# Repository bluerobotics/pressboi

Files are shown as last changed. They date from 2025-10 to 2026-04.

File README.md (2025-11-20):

<div align="center">

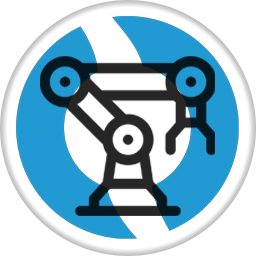
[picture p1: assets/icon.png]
Pressboi


# Pressboi

**Dual-Motor Press Control System**






[View Changelog](CHANGELOG.md) • [Download Latest Release](https://github.com/bluerobotics/pressboi/releases/latest)

</div>

---

## Overview

Firmware for the Pressboi dual-motor press control system, built on the Teknic ClearCore platform. This firmware provides precision control for press operations with real-time force monitoring, synchronized dual-motor movement, and network/USB communication.

**Designed to work with:** [BR Equipment Control App](https://github.com/bluerobotics/br-equipment-control-app) - A Python/Tkinter GUI for controlling and monitoring the Pressboi and other Blue Robotics manufacturing equipment.

## Features

- **Dual-motor synchronized control** - Two motors on a single axis for press operations
- **UDP/Ethernet communication** - Network-based control with device discovery
- **USB Serial fallback** - Direct USB communication support
- **Command-based control** - Simple text-based command protocol
- **Real-time telemetry** - Position, force, torque, and status reporting
- **Pause/resume/cancel** - Interrupt and resume operations safely
- **Force monitoring** - Real-time force feedback with configurable limits
- **Auto-generated protocol** - Commands and telemetry from JSON schemas

---

## Building

### Requirements

- **Atmel Studio 7** (Windows) or compatible ARM GCC toolchain
- **Teknic ClearCore libraries** (included as submodules/dependencies)
  - `libClearCore`
  - `LwIP` (Lightweight IP stack)

### Build Instructions

1. Open `pressboi.atsln` in Atmel Studio
2. Ensure libraries are properly referenced:
   - `lib/libClearCore/ClearCore.cppproj`
   - `lib/LwIP/LwIP.cppproj`
3. Select build configuration (Debug or Release)
4. Build the solution (F7)

### Output Files

- `Debug/pressboi.bin` - Binary firmware image
- `Debug/pressboi.uf2` - UF2 format for bootloader flashing

### Flashing

### Via BR Equipment Control App (Recommended for Updates)

The easiest way to update firmware on an already-running device is through the [BR Equipment Control App](https://github.com/bluerobotics/br-equipment-control-app):

1. Open the Firmware Manager in the app
2. Select your device
3. Choose the firmware file or download the latest release
4. Click "Update Firmware" - the app handles the entire flashing process automatically

**Note:** Firmware flashing is only supported over USB connections. For initial flashing of a new device, use the bootloader method below.

### Via Bootloader (For Initial Flashing)

For initial flashing of a new device or when the app is not available:

1. Put the ClearCore into bootloader mode (hold button during power-on)
2. Copy `pressboi.uf2` to the mounted bootloader drive
3. The device will automatically reboot with new firmware

### Via Atmel Studio

1. Connect ClearCore via USB
2. Select "Custom Programming Tool" in project settings
3. Build and program (F5)

---

## Communication Protocol

The firmware uses a simple text-based command protocol over UDP or USB serial:

- Commands: `move_abs <position> mm`, `move_inc <distance> mm`, `home`, `enable`, `disable`
- Status: `DONE: <command>`, `ERROR: <message>`, `INFO: <message>`
- Telemetry: Periodic status updates with position, force, torque, and motor status

See the [BR Equipment Control App](https://github.com/bluerobotics/br-equipment-control-app) for full protocol documentation and command reference.

---

## Hardware Configuration

### Motors
- **Motor A**: Primary press motor (M0)
- **Motor B**: Secondary press motor (M1) - synchronized with Motor A

### Sensors
- **Force sensor**: Load cell or motor torque-based force monitoring
- **Position feedback**: Encoder feedback from ClearPath motors

## Configuration

Key parameters can be configured in `inc/config.h`:

- **Motor parameters**: Steps per mm, velocities, accelerations, torque limits
- **Homing parameters**: Velocities, accelerations, torque limits, backoff distances
- **Force monitoring**: Force limits, sensor calibration, enable/disable options
- **Network settings**: UDP port, packet sizes, telemetry interval

---

## Contributing

For issues, feature requests, or contributions, please open an issue or pull request on GitHub.

---

<div align="center">

⭐ **Star us on GitHub if you found this useful!**

Made with 💙 by the Blue Robotics team and contributors worldwide

---

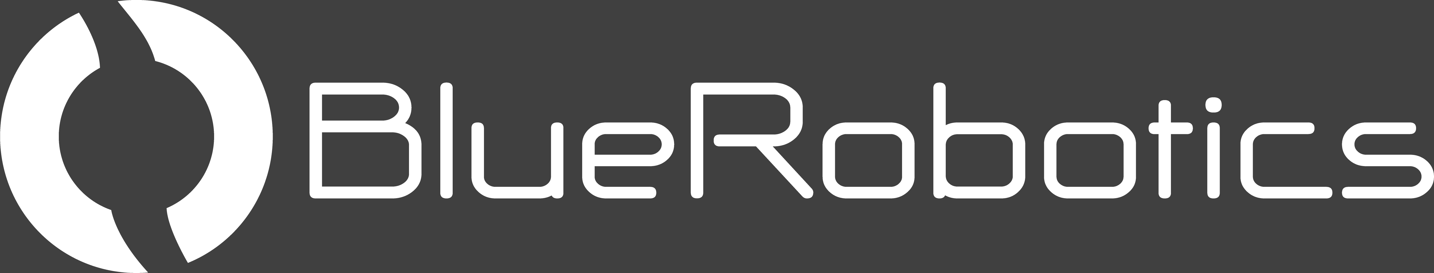
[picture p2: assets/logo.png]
Blue Robotics


**[bluerobotics.com](https://bluerobotics.com)** | Manufacturing Equipment Control

</div>

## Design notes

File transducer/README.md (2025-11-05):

# HX711 Force Transducer Interface

Rugeduino (Arduino Uno) firmware for interfacing HX711 load cell amplifier with Pressboi ClearCore controller.

## Hardware Required

- **Ruggeduino-SE ST** (Screw Terminal version - ruggedized Arduino Uno)
- **HX711 Load Cell Amplifier Module**
- **Load Cell** (configured for force measurement)
- 22-24 AWG wire for screw terminal connections

## Wiring

### Load Cell → HX711

```
Load Cell Color    HX711 Pin
---------------    ---------
Red (E+)       →   E+
Black (E-)     →   E-
White (A-)     →   A-
Green (A+)     →   A+
```

### HX711 → Ruggeduino-SE

**Use the screw terminals - no soldering required!**

```
HX711 Pin      Ruggeduino-SE Screw Terminal
---------      ----------------------------
VCC        →   5V
GND        →   GND
DOUT       →   D3
SCK        →   D2
RATE       →   5V (enables 80Hz mode; leave disconnected for 10Hz)
```

### Rugeduino → ClearCore COM-0

**ClearCore COM-0 must be configured in TTL mode!**

```
Ruggeduino-SE Pin    ClearCore COM-0 (8-pin connector)         Wire Color
-----------------    ----------------------------------         ----------
D1 (TX)          →   Pin 8 (Data In / COM0 RX)                 Brown
D0 (RX)          →   Pin 5 (Data Out / COM0 TX)                Green/White
GND              →   Pin 4 (GND)                               Blue
VIN or 5V        →   Pin 6 (5V Power) ⚡ 450mA available       Green
```

**Note:** 
- The ClearCore COM-0 port can power the Ruggeduino-SE directly (up to 450mA available from 5VOB). Connect to VIN or 5V screw terminal. Ruggeduino draws ~50mA typical.
- **During USB programming:** Disconnect D0/D1 from ClearCore to avoid conflicts with USB serial

## Software Setup

### Arduino

1. Install the **HX711 library** by Bogde:
   - Arduino IDE → Tools → Manage Libraries
   - Search "HX711"
   - Install "HX711 by Bogde"

2. Upload `hx711_nano.ino` to the Ruggeduino-SE
   - **Important:** Disconnect D0/D1 from ClearCore during USB upload

3. **Calibrate the scale:**
   - Set `calibration_factor = 1.0` initially
   - Place a known weight (e.g., 10 kg) on the load cell
   - Read the output in Serial Monitor
   - Calculate: `calibration_factor = output_value / 10.0`
   - Update the code and re-upload

### ClearCore

The force sensor is integrated into the pressboi firmware:
- `force_sensor.h` / `force_sensor.cpp` - Force sensor class
- COM-0 configured as TTL UART at 115200 baud
- Force readings automatically appear in telemetry

## Serial Protocol

### Arduino → ClearCore (Continuous Output)

**Format:** Simple floating point value in kg  
**Example:** `12.34\n`  
**Rate:** 80Hz (synchronized with HX711 samples when RATE pin = 5V)

### ClearCore → Arduino (Commands)

| Command | Function |
|---|---|
| `T` or `t` | Tare/zero the scale |
| `R` or `r` | Get raw ADC value (for debugging) |
| `C` or `c` | Calibration mode (future) |

## Calibration Procedure

1. **Tare with no load:**
   - Remove all weight from load cell
   - Send 'T' command or power cycle
   - Reading should be ~0.00 kg

2. **Determine calibration factor:**
   - Set `calibration_factor = 1.0` in code
   - Upload to Arduino
   - Place known weight (e.g., 10.00 kg)
   - Read the output value (e.g., 234567)
   - Calculate: `calibration_factor = 234567 / 10.0 = 23456.7`
   - Update code with new factor and re-upload

3. **Verify accuracy:**
   - Test with multiple known weights
   - Adjust calibration factor if needed
   - Typical accuracy: ±0.1% with proper calibration

## Troubleshooting

**No readings:**
- Check wiring connections
- Verify HX711 power (3.3V-5V)
- Check Arduino serial output in Serial Monitor
- Ensure load cell is properly connected

**Noisy/unstable readings:**
- Improve grounding
- Shorten wires between load cell and HX711
- Use shielded cable for load cell wires
- Reduce mechanical vibration

**Readings drift:**
- Allow 10-15 minutes warm-up time
- Reduce temperature variations
- Re-tare periodically

**Readings don't change with force:**
- Check load cell wiring (especially A+/A-)
- Verify load cell is mechanically loaded correctly
- Check calibration factor

## References

- **HX711 Datasheet:** https://cdn.sparkfun.com/assets/b/f/5/a/e/hx711F_EN.pdf
- **HX711 Library:** https://github.com/bogde/HX711
- **SparkFun Hookup Guide:** https://learn.sparkfun.com/tutorials/load-cell-amplifier-hx711-breakout-hookup-guide

## License

MIT License - See main repository LICENSE file

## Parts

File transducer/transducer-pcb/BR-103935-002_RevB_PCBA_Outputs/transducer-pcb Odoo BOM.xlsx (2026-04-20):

External ID | Reference | Product | Quantity | BoM Type | BoM Lines/Component | BoM Lines/Quantity
mrp_bom_BR-103935-002 | BOM_PCB | BR-103935-002 | 1 | Manufacture this product | component.bre_BRE_000048 | 1
mrp_bom_BR-103935-002 | BOM_PCB | BR-103935-002 | 1 | Manufacture this product | component.bre_BRE_001269 | 1
mrp_bom_BR-103935-002 | BOM_PCB | BR-103935-002 | 1 | Manufacture this product | component.bre_BRE_001271 | 2
mrp_bom_BR-103935-002 | BOM_PCB | BR-103935-002 | 1 | Manufacture this product | component.bre_BRE_001364 | 1
mrp_bom_BR-103935-002 | BOM_PCB | BR-103935-002 | 1 | Manufacture this product | component.bre_BRE_001029 | 2
mrp_bom_BR-103935-002 | BOM_PCB | BR-103935-002 | 1 | Manufacture this product | component.bre_BRE_001259 | 2
mrp_bom_BR-103935-002 | BOM_PCB | BR-103935-002 | 1 | Manufacture this product | component.bre_BRE_001332 | 2
mrp_bom_BR-103935-002 | BOM_PCB | BR-103935-002 | 1 | Manufacture this product | component.bre_BRE_001042 | 1

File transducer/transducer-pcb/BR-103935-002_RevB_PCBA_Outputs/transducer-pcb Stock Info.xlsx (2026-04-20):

# Boards: | 5 | <---- EDIT NUMBER OF BOARDS HERE
Project: | transducer-pcb
BR Number: | BR-103935-002 RevB
Date: | 2026-02-23T16:28:30-0800
Legend
In stock @ JLC
Low Stock @ JLC
Not Enough Stock @ JLC
Does not exist @ JLC
BRE Number | Reference | Description | Quantity/Board | Total Quantity | MPN | JLCPCB Part # | JLC Stock | Global + Consigned Stock | Alt JLC Parts | DigiKey Parts | Mouser Parts | Other Vendor Parts | Unit Cost | Cost Per Board
BRE-000048 | C1 | 1nF 1kV X7R 10% Ceramic Capacitor 0805 | 1 | 5 | 0805B102K102CT | C303890 | 900 | 0 |  | 1292-0805B102K102CT-ND | 791-0805B102K102CT |  | $0.0037 | $0.0037
BRE-001269 | J1 | 1x4P 7A 150V 2.54mm Screw Terminal Through Hole | 1 | 5 | DB125-2.54-4P-GN-S | C918122 | 80 | 940 |  |  |  |  | $0.26 | $0.26
BRE-001271 | J2, J11 | 1x2P 8A 130V 2.54mm Screw Terminal Through Hole | 2 | 10 | KF128-2.54-2P | C474920 | 90 | 0 |  |  |  |  | $0.11 | $0.21
BRE-001364 | J3 | RJ45 Receptacle Connector, Without LEDs, Unshielded | 1 | 5 | RC02015 | C708654 | 30 | 0 |  |  |  |  | $0.20 | $0.20
BRE-001029 | J4, J5 | Header Pin Connector 01x05 2.54mm (0.100") Vertical PTH | 2 | 10 | HB-PH3-25415PB2GOP | C6332198 | 75 | 0 |  |  |  |  | $0.01 | $0.03
BRE-001259 | J6, J8 | Header Pin 2P 01x02P 2.54mm Pitch Vertical Through Hole 3A | 2 | 10 | PZ254V-11-02P | C492401 | 1250 | 0 |  |  |  |  | $0.01 | $0.01
BRE-001332 | J7, J9 | Header Pin Connector 01x06 2.54mm (0.100") Vertical PTH | 2 | 10 | PZ2.54-1X6P-H25 | C42431790 | 0 | 0 |  |  |  |  | $0.00 | $0.00
BRE-001042 | J10 | Header Pin Connector 01x04 2.54mm (0.100") Vertical PTH | 1 | 5 | PZ254V-11-04P | C2691448 | 0 | 0 | C6332197, C5116483 |  |  |  | $0.00 | $0.00
 |  |  |  |  |  |  |  |  |  |  |  |  | Total BOM Cost: | $0.72
DNP Components
BRE Number | Reference | Description | Quantity/Board | Total Quantity | MPN | JLCPCB Part # | JLC Stock | Global + Consigned Stock | Alt JLC Parts | DigiKey Parts | Mouser Parts | Other Vendor Parts | Unit Cost | Cost Per Board

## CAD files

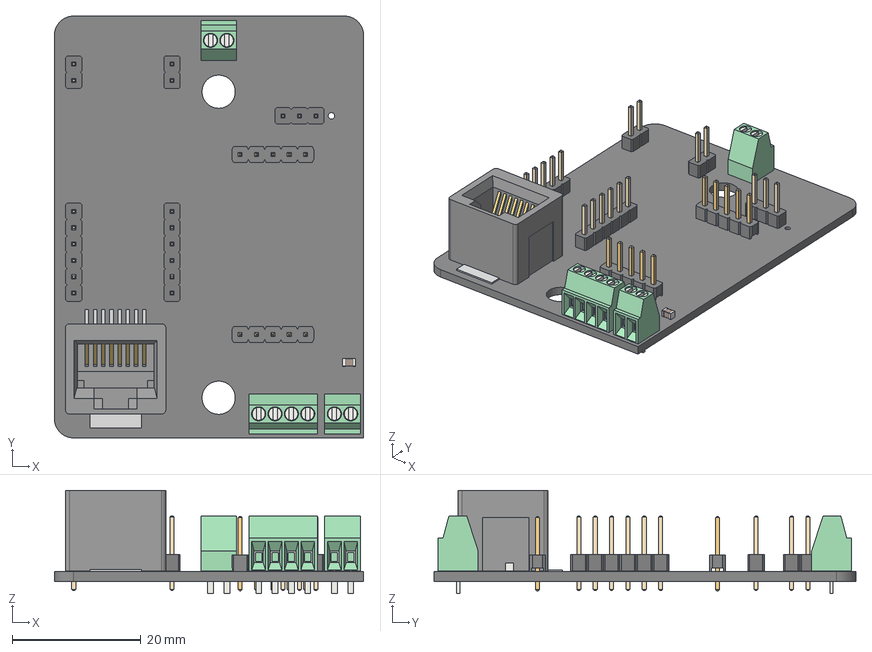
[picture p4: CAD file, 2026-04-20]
transducer/transducer-pcb/BR-103935-002_RevB_PCBA_Outputs/transducer-pcb.step
48.0 x 65.5 x 16.0 mm
PinHeader_1x06_P2.54mm_Vertical x 2
6130xx11121_PIN x 10
C_0805_2012Metric
TerminalBlock_Phoenix_MPT-0,5-2-2.54_1x02_P2.54mm_Horizontal x 2
PinHeader_1x02_P2.54mm_Vertical x 2
PinHeader_1x03_P2.54mm_Vertical
RJ45-SMD_8P-P1.27_RC02015
TerminalBlock_Phoenix_MPT-0,5-4-2.54_1x04_P2.54mm_Horizontal
transducer-pcb_PCB

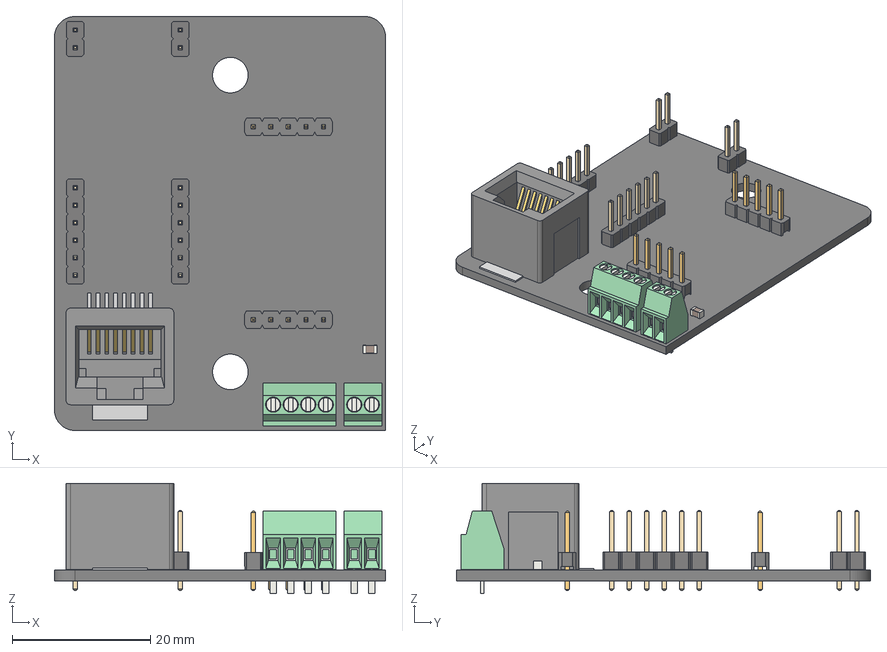
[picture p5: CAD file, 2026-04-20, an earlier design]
transducer/transducer-pcb/BR-103935-002_RevA_PCBA_Outputs/transducer-pcb.step
48.0 x 60.0 x 16.0 mm
PinHeader_1x06_P2.54mm_Vertical x 2
6130xx11121_PIN x 10
C_0805_2012Metric
PinHeader_1x02_P2.54mm_Vertical x 2
RJ45-SMD_8P-P1.27_RC02015
TerminalBlock_Phoenix_MPT-0,5-2-2.54_1x02_P2.54mm_Horizontal
TerminalBlock_Phoenix_MPT-0,5-4-2.54_1x04_P2.54mm_Horizontal
transducer-pcb_PCB

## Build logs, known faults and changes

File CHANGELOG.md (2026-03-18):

# Changelog

All notable changes to the Pressboi firmware will be documented in this file.

## [1.14.1] - 2026-03-18

### Fixed
- **NVM strain calibration persistence**: `set_strain_cal` command was writing coefficients to wrong NVM addresses (`(8+i)` instead of `(8+i)*4` byte offsets), causing calibration to be lost on reboot
- **Telemetry force display**: `force_motor_torque` telemetry was using hardcoded calibration values (1.04/0.0335) instead of NVM-stored values from `set_force_offset`/`set_force_scale` commands; also increased force clamp from 1000 kg to 2000 kg to match motor_torque mode range

### Changed
- **Dead code cleanup**: Removed unused USB mirror declarations and member variables from CommsController (~1KB RAM savings)

## [1.14.0] - 2025-11-28

### Added
- **Press Report System**: HTML report generation with interactive graphs
  - Force vs distance visualization with Plotly.js
  - 4th order polynomial fit for machine strain calibration
  - Pass/fail thresholds for force, endpoint, and energy
  - Collapsible calibration data section with copy command button
- **`set_press_threshold` command**: Configure force threshold for press detection (0.1-50.0 kg), saved to NVM
- **`set_strain_cal` command**: Set machine strain compensation coefficients, saved to NVM
- **Telemetry**: Added `startpoint`, `endpoint`, and `press_threshold` telemetry values
- **NVM Storage**: Press threshold and strain calibration coefficients persisted across reboots

### Changed
- **Default press threshold**: 2.0 kg (configurable via command)
- **Machine strain coefficients**: Updated defaults for improved energy accuracy
- **Max deflection**: Increased `MACHINE_STRAIN_MAX_DEFLECTION_MM` to 5.0mm for flexible jigs

### Fixed
- **Joules calculation**: Fixed machine strain compensation consuming all energy
- **Endpoint tracking**: Now correctly reports actual endpoint position via telemetry

## [1.13.0] - 2025-11-26

### Added
- **Operator View**: Cycle time display, error/warning status bar, "Show Stats" button
- **Operator View**: On-screen keyboard support (Mac only)
- **Operator View**: Hover effects on Run/Hold/Reset buttons matching main app

## [1.12.1] - 2025-11-26

### Changed
- **Operator View**: Redesigned press operator view with fullscreen layout, large controls, and PASS/FAIL indicator

### Fixed
- **CRITICAL: Watchdog timeout on app restart**: Delayed auto-homing by 2 seconds after boot to prevent watchdog timeout during busy startup/reconnection period when message queues are processing and USB is reconnecting

## [1.12.0] - 2025-11-26

### Added
- **`home_on_boot` command**: Configure whether press automatically homes on startup (default: true), saved to NVM
- **Retract position persistence**: `set_retract` now saves position to NVM and restores after power cycle/reboot

### Changed
- **NVM dump enhanced**: Added `HomeOnBoot` and `RetractPosition` to dump summary output

### Fixed
- **Command parsing order**: Fixed `reset_nvm` being misinterpreted as `reset` by checking longer commands first
- **Retract position restoration**: Correctly recalculates retract position after homing to prevent accumulation

## [1.11.3] - 2025-11-26

### Changed
- **Watchdog timeout increased to 256ms**: Doubled from 128ms to provide better stability during USB reconnection
- **USB chunking timeout reduced**: Lowered per-chunk timeout from 10ms to 3ms to prevent blocking (total ~30ms vs previous ~100ms)

### Fixed
- **Watchdog timeout on app restart**: Prevents main loop blocking during USB reconnection when TX queue processes large messages

## [1.11.2] - 2025-11-24

### Changed
- **NVM dump output**: Added polarity information to `dump_nvm` command summary

## [1.11.1] - 2025-11-24

### Changed
- Updated compiled binaries with latest source changes

## [1.11.0] - 2025-11-24

### Added
- **`set_polarity` command**: Allows flipping coordinate system between 'normal' and 'inverted' modes, saved to NVM

## [1.10.5] - 2025-11-21

### Fixed
- **TX queue overflow during log dumps**: Temporarily disable watchdog during `dump_error_log` command to prevent resets during large log transfers (100+ entries can take >500ms, exceeding 100ms watchdog timeout)
- **Log dump reliability**: Added 5ms delay per error entry and 50ms delay every 10 heartbeat entries to prevent TX queue overflow errors
- Watchdog disabled only for diagnostic `dump_error_log` command, maintains watchdog integrity for all normal operations

## [1.10.1] - 2025-11-20

### Added
- **Extended watchdog breadcrumbs**: Added `NETWORK_REFRESH`, `USB_SEND`, `USB_RECONNECT`, and `USB_RECOVERY` breadcrumbs for finer-grained watchdog timeout diagnostics

### Fixed
- **CRITICAL: Unbounded network processing**: Limited `EthernetManager::Refresh()` to process maximum 10 packets per call, preventing watchdog timeouts when network accumulates many packets during USB reconnection
- **Unbounded UDP processing**: Limited `processUdp()` to process maximum 10 UDP packets per call, preventing main loop from blocking >128ms
- **USB recovery watchdog feeding removed**: Removed watchdog feeds during USB port recovery operations - if USB operations hang, watchdog should fire to recover system (feeding defeats the purpose of the watchdog)
- **Watchdog timeout on USB reconnection**: USB host reconnection and message sending now properly tracked with breadcrumbs, allowing identification of exactly where blocking occurs

## [1.10.0] - 2025-11-20

### Added
- **Error logging system**: Circular buffer with 100 entries (8.8KB) supporting DEBUG/INFO/WARN/ERROR/CRITICAL levels
- **Heartbeat log**: 24-hour USB/network status tracker (2880 × 8-byte entries, 23KB) recorded every 30 seconds
- **`dump_error_log` command**: Retrieve diagnostic logs via USB or network
- **USB auto-recovery**: Detects stuck TX buffer (2s timeout) and automatically reopens port with watchdog protection

### Changed
- **Motor fault detection**: 500ms grace period after clearing faults prevents false alarms during status register stabilization

### Fixed
- **Watchdog timeout during USB recovery**: Removed blocking delay and added watchdog feeds during port operations
- **Double-reset requirement**: Single RESET command now properly clears watchdog recovery state
- **USB connection persistence**: Auto-recovery eliminates need for power cycle after app restart

## [1.9.0] - 2025-11-19

### Changed
- **Multi-step command handling**: Commands with `force_action=retract` now send a single DONE message only when the entire sequence (move + retract) completes
  - Move completion sends INFO message: "Move complete, retracting..." or "Force limit reached, retracting..."
  - DONE message sent only when retract finishes, using original command name (e.g., `DONE: move_abs`)
  - Simplifies app-side logic - app waits for one DONE per command regardless of internal steps
  - Makes firmware responsible for its own multi-step command flow

## [1.8.5] - 2025-11-19

### Fixed
- **USB host detection**: Fixed USB connection health check only running when messages were queued, causing firmware to stay in "disconnected" state after app restart without power cycle. Health check now runs every loop iteration regardless of queue state, ensuring prompt reconnection detection.

## [1.8.4] - 2025-11-19

### Fixed
- **USB buffer management**: Modified `notifyUsbHostActive()` to clear the TX queue and flush USB input buffer when a USB command is received, preventing stale messages from accumulating

## [1.8.3] - 2025-11-19

### Fixed
- **Watchdog timeouts**: Fixed watchdog timer triggering during USB host detection and reconnection by queueing messages instead of blocking on `ConnectorUsb.Send()`
- **USB reconnection**: USB host reconnection message now only sends when sufficient buffer space is available (>40 bytes) to prevent blocking

## [1.8.2] - 2025-11-19

### Fixed
- **USB host detection**: Fixed USB host connection tracking not resetting properly when receiving commands, causing firmware to remain in "host disconnected" state after app restart without power cycle

## [1.8.1] - 2025-11-19

### Fixed
- **USB host detection**: Moved USB connection state variables from static to class members to ensure proper state management across app restarts

## [1.8.0] - 2025-11-19

### Fixed
- **USB buffer improvements**: Implemented automatic USB host connection detection to prevent buffer overflow
- **Message filtering**: Firmware now only sends USB/network messages when respective interfaces have active listeners

### Changed
- **Device naming portability**: Replaced hardcoded "PRESSBOI" strings with `DEVICE_NAME_UPPER` and `DEVICE_NAME_LOWER` defines from `config.h`

## [1.7.0] - 2025-11-18

### Changed
- **Device definition restructuring**: Moved device definition from Equipment Control App to firmware repository
  - Command definitions, telemetry schemas, and GUI layouts now live in `pressboi/definition/` folder
  - Versioning of device protocol now happens alongside firmware
  - Equipment Control App automatically discovers and loads definitions from device paths
  - Supports both standalone definition folders and definitions embedded in firmware repos

### Fixed
- **USB telemetry**: Fixed firmware not sending telemetry over USB serial when GUI not discovered via network
- **USB message buffer**: Implemented chunked message sending for telemetry packets larger than 64-byte USB CDC buffer
- **Network discovery**: Fixed firmware accepting discovery commands even when GUI already discovered, allowing reconnection
- **Retract position telemetry**: Fixed `retract_pos` reporting garbage values when motor not homed (now reports 0.0)
- **Dual connection support**: Both USB and network telemetry now stream simultaneously when both connections present

## [1.6.1] - 2025-11-17

### Changed
- **Repository structure**: Reorganized project layout - moved libraries to `lib/` folder and flattened `pressboi/` subfolder to root
- **Build system**: Updated project paths to reflect new library locations

## [1.6.0] - 2025-11-15

### Added
- **Endpoint telemetry**: New `endpoint` variable records the exact position (mm) where press moves stop

### Fixed
- **CRITICAL**: Fixed infinite retract loop that caused watchdog timeouts when using `retract` or `abort` force actions.
- Fixed `abort` force action to only trigger retract when force limit is actually hit. Previously, `abort` action would retract even when the move completed normally without hitting the force limit.
- Fixed zero-step moves causing timeout errors. Moves with 0 steps now immediately return `DONE` instead of attempting to execute and timing out.

### Changed
- Updated `force_action` parameter documentation to clarify behavior: `retract` always retracts on any completion, `abort` only retracts when force limit is hit.

## [1.5.0] - 2025-11-14

### Added
- **USB serial communication**: Commands and telemetry now mirrored to USB serial (ConnectorUsb) alongside network communication
- **Dual-channel command processing**: USB commands processed identically to network commands through unified dispatcher

### Changed
- **Lowercase status text**: Main state and motor status use lowercase for consistency (`standby`, `busy`, `error`, `enabled`, `disabled`, `homed`, `not homed`)
- **USB processing limit**: Characters per call capped at 32 to prevent watchdog timeout (128ms threshold)

## [1.4.2] - 2025-11-13

### Added
- **Force zeroing**: new `set_force_zero` command lets the controller automatically tare either the load cell or the motor-torque force model

## [1.4.1] - 2025-11-07

### Added
- **Bootloader control**: `reboot_bootloader` command drops the controller into ClearCore UF2 mode, enabling remote flashes from the Equipment Control app.
- **Discovery metadata**: discovery responses now include the running firmware version so tooling can detect when an update is available.

## [1.4.0] - 2025-11-07

### Added
- **Force mode commands**: new `set_force_mode`, `set_force_offset`, `set_force_scale`, and `set_strain_cal` commands
- **Press energy integration**: incremental net force × travel accumulation for Joule reporting
- **Machine compliance model**: 4th-order strain calibration accounts for machine deflection in energy calculation
- **Contact thresholding**: 3 kg engagement gate aligns compensation with real workpiece contact
- **Persistent calibration**: non-volatile memory stores calibration constants and force-mode selection (load-cell vs motor torque)
- **Bootloader control**: `reboot_bootloader` command drops directly into ClearCore UF2 mode for automated flashing
- **Discovery metadata**: discovery responses now advertise firmware version for app-side upgrade prompts

### Changed
- **Force mode**: move commands drop the `force_mode` argument; new `set_force_mode` selects sensor source globally
- **Better precision**: doubled math for position/energy and telemetry now reports millimeters with three decimals
- **Retract control**: `set_retract` accepts optional speed (default 25 mm/s) and force-action retracts honour that rate
- **Force mode behaviour**: load-cell moves keep default torque limit while motor-torque mode still uses calibrated curve

### Fixed
- **Retract speed on force action**: force-action retracts now run at the configured retract speed instead of the previous slow fallback rate

## [1.3.0] - 2025-11-06

### Added
- **Hardware watchdog timer** (SAMD51 WDT): 128ms timeout, eses RSTC->RCAUSE register to detect watchdog resets
- **STATE_RECOVERED**: Motors disabled after watchdog timeout until explicit reset
- **test_watchdog command**: Intentionally blocks to trigger watchdog for testing
- **Non-blocking reset**: STATE_RESETTING now uses non-blocking delay to avoid WDT trip
- **Motor torque force limiting**: `motor_torque` mode uses motor HLFB as force limit (no load cell required)
- **Torque-to-force conversion**: `Torque% = 0.0335 × kg + 1.04` (50-1000 kg range)
- **Force mode parameter**: Move commands accept `force_mode` (`motor_torque` or `load_cell`)
- **Split force telemetry**: `force_load_cell` and `force_motor_torque` fields
- **Force source field**: Telemetry indicates active mode (`load_cell` or `motor_torque`)

### Changed
- **Watchdog functions**: Modularized into dedicated recovery, init, feed, and clear functions
- **Limit handling**: `handleLimitReached()` centralizes retract/skip/hold logic for both force modes
- **Load cell checks**: Only runs in `load_cell` mode; `motor_torque` mode operates independently
- **Force limits**: Execute `force_action` (retract/skip/hold) on limit instead of throwing errors
- **Motor enable reporting**: Uses internal `m_isEnabled` flag instead of hardware register
- **Torque telemetry**: Single `torque_avg` field (average of both motors)

### Fixed
- **Torque flickering**: Holds last non-zero value during active moves

## [1.2.1] - 2025-11-04

### Added
- `FORCE_SENSOR_ENABLED` configuration flag in config.h to support machines without force transducers
- Documentation in README for force sensor configuration

### Changed
- Force sensor checks now conditional based on `FORCE_SENSOR_ENABLED` flag
- Machines without force transducers can now operate normally by setting flag to `false`

## [1.2.0] - 2025-11-04

### Added
- Pause and resume functionality for move operations (move_abs, move_inc, retract)
- Move parameter storage for proper pause/resume state tracking
- Move start time tracking for timeout detection
- Force transducer integration with HX711 load cell
- Force-based move control with configurable actions (hold, skip, retract)
- Real-time force monitoring during moves with configurable force limits

### Changed
- State transition logic reordered to check motor status before timeout evaluation
- Resume operation now recalculates remaining steps at resume time (not pause time)
- Force parameter now fully functional (previously temporarily ignored)

### Fixed
- **Critical:** Fixed premature DONE messages - moves no longer send DONE immediately after START
- **Critical:** Fixed move timeout errors - `m_moveStartTime` now properly initialized for all moves
- Fixed resume calculation to use current position instead of stale pause-time position
- Fixed state machine to properly track STARTING → ACTIVE → completion transitions
- Move parameters (initial position, target steps, velocity, acceleration, torque) now properly stored for all move types

## [1.1.0] - 2025-11-03

### Added
- Reset command (replaces clear_errors) for system recovery
- Target position telemetry tracking for all move commands
- Speed limiting (100 mm/s maximum)
- Standardized DONE messages for all commands (enable, disable, home, moves, pause, resume, cancel, reset)

### Changed
- Cancel command now handles emergency stops (abort command removed)
- Force parameter temporarily ignored until force transducer implementation (uses default torque limit)
- Improved command parsing reliability

### Fixed
- Target position now updates correctly during moves (was always 0)
- Code generator permanently fixed for enum comma placement
- All autogenerated files compile without warnings

## [1.0.2] - 2025-11-03

### Added
- MIT License file
- License section in README

### Fixed
- License badge in README now displays correctly
- Release badge styling improved

## [1.0.1] - 2025-11-03

### Changed
- Enhanced README with comprehensive class and method documentation
- Added Blue Robotics and Pressboi logos
- Added detailed flashing instructions for Microchip Studio with Atmel ICE
- Added debugging workflow documentation
- Reorganized flashing methods by use case (development vs field updates)
- Added link to BR Equipment Control App
- Improved visual layout and community engagement footer

## [1.0.0] - 2025-11-03

### Added
- Initial release of Pressboi press control firmware
- Dual-motor synchronized control for press operations
- UDP/Ethernet communication with discovery protocol
- USB Serial communication support
- Command system: home, move_abs, move_inc, set_start_pos, move_to_start, enable, disable
- Pause/resume/cancel operations for any active move
- Real-time telemetry reporting (position, force, torque, motor status)
- Homing routines with configurable parameters
- Force limiting and monitoring
- State machine-based operation for reliable control

### Technical Details
- Based on ClearCore platform (SAME53 microcontroller)
- Communication: UDP port 8888, USB Serial
- Command parser with parameter extraction
- Circular message queues for Rx/Tx
- Auto-generated protocol files from JSON schemas

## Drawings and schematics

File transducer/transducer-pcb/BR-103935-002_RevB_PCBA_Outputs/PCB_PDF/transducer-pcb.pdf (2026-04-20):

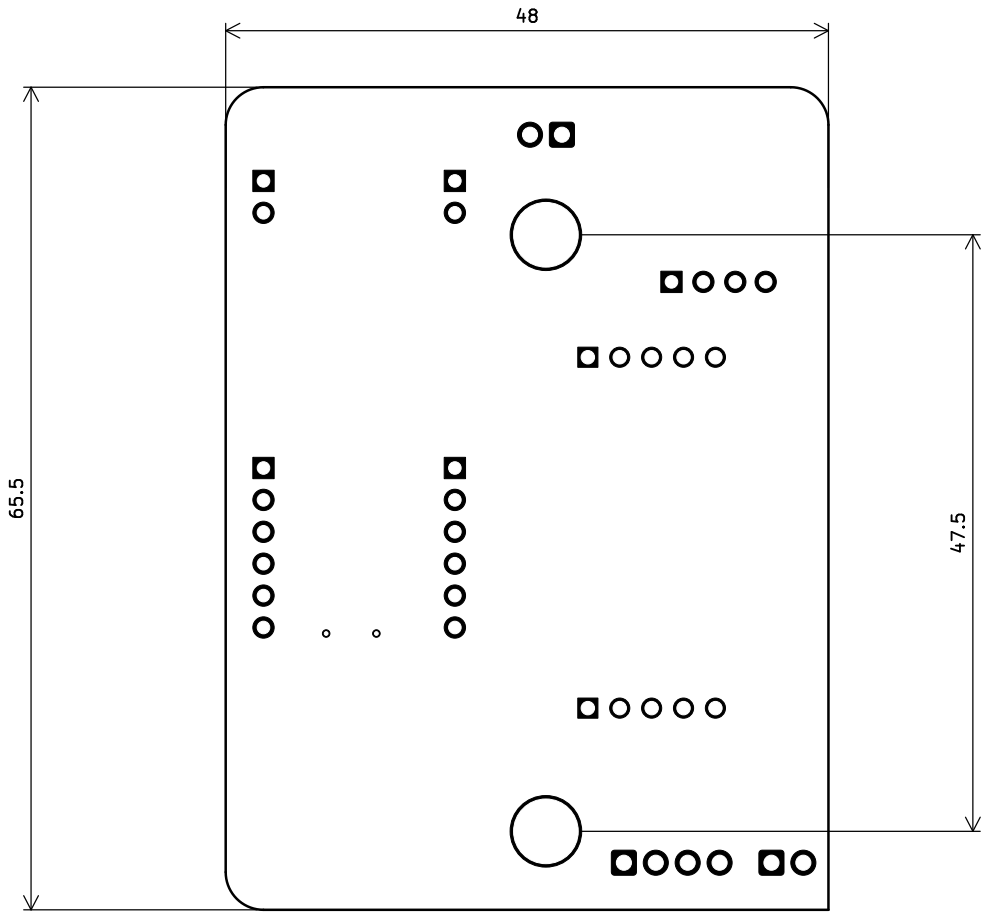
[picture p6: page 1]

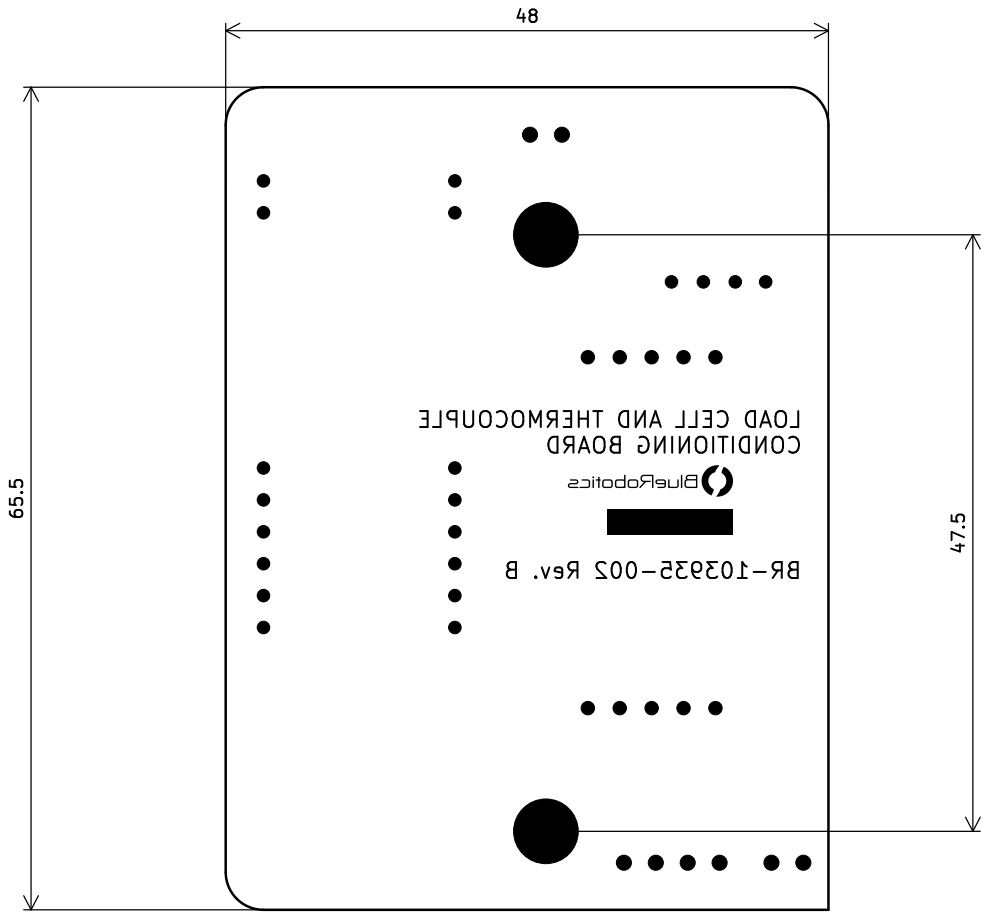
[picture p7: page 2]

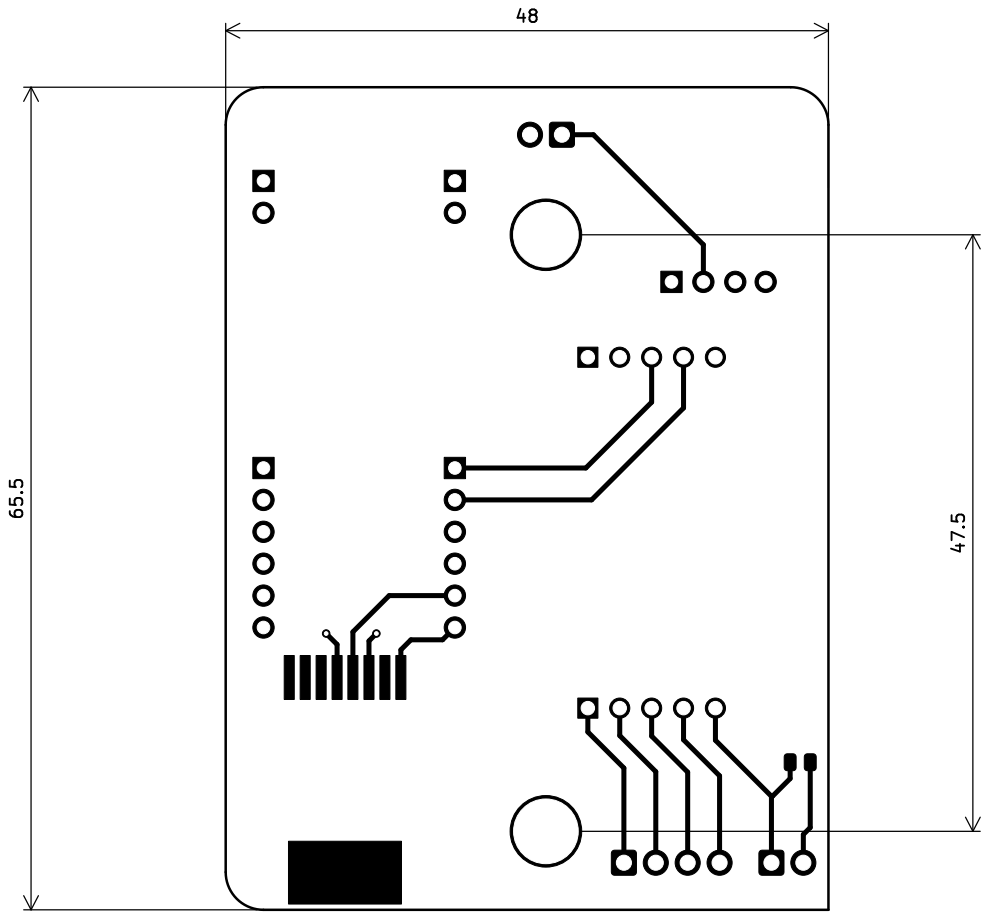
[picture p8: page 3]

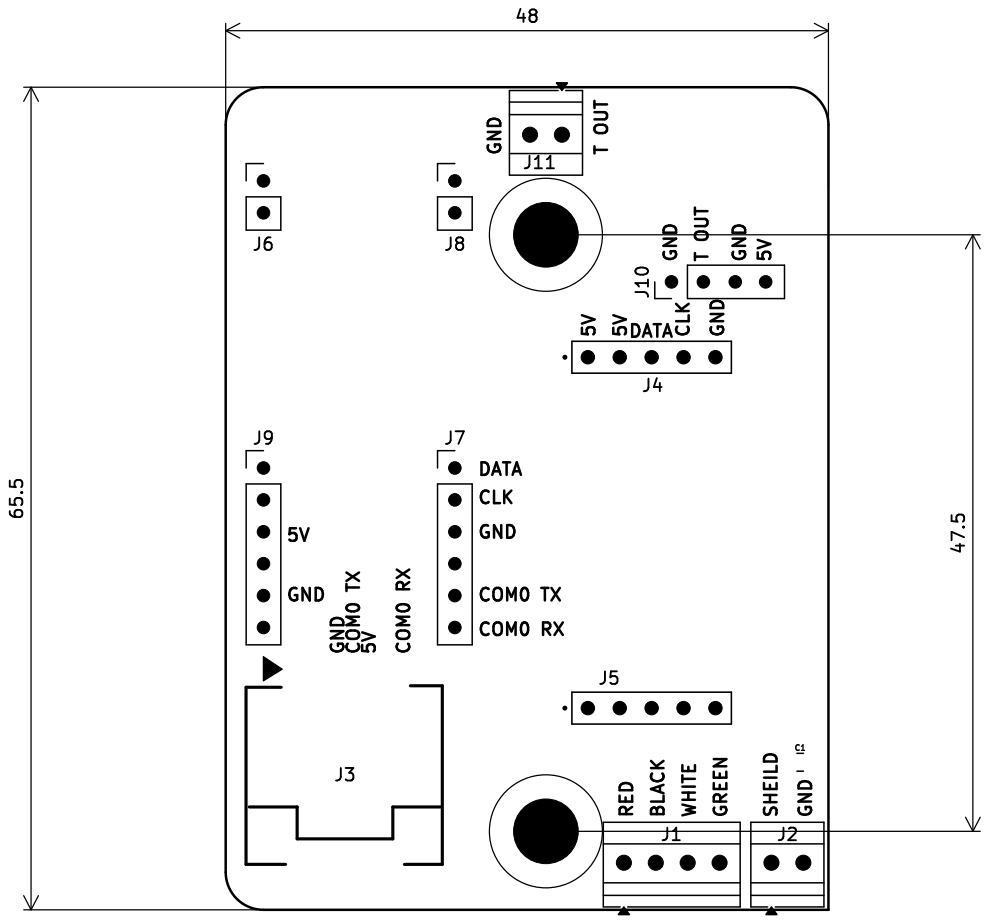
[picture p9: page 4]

T OUT GND 5V 5V CLK GND 5V

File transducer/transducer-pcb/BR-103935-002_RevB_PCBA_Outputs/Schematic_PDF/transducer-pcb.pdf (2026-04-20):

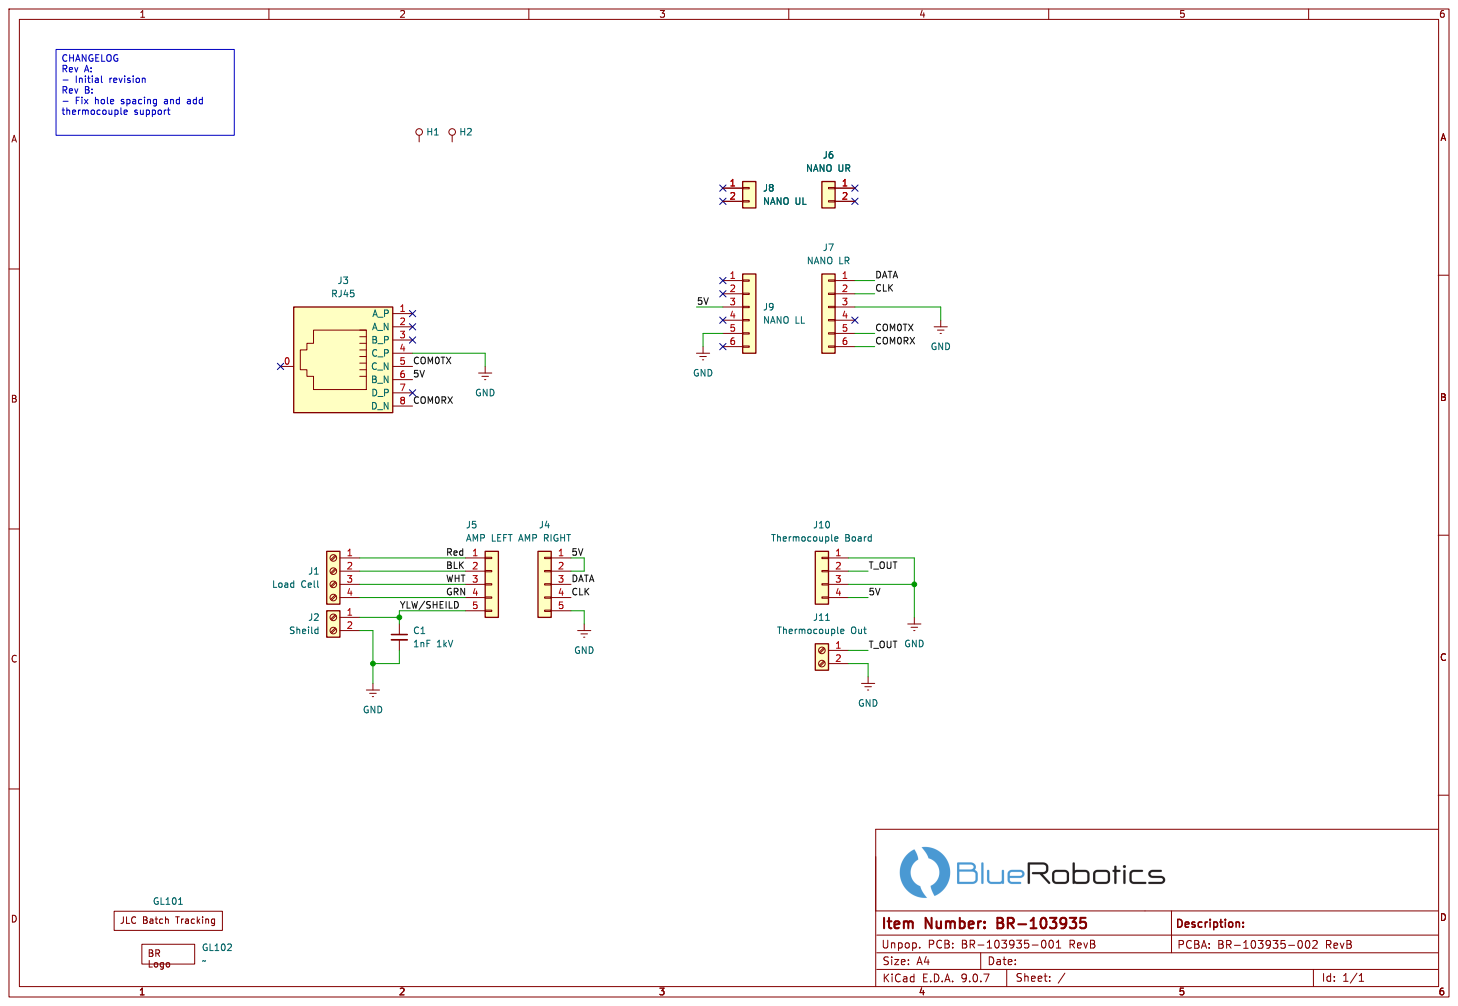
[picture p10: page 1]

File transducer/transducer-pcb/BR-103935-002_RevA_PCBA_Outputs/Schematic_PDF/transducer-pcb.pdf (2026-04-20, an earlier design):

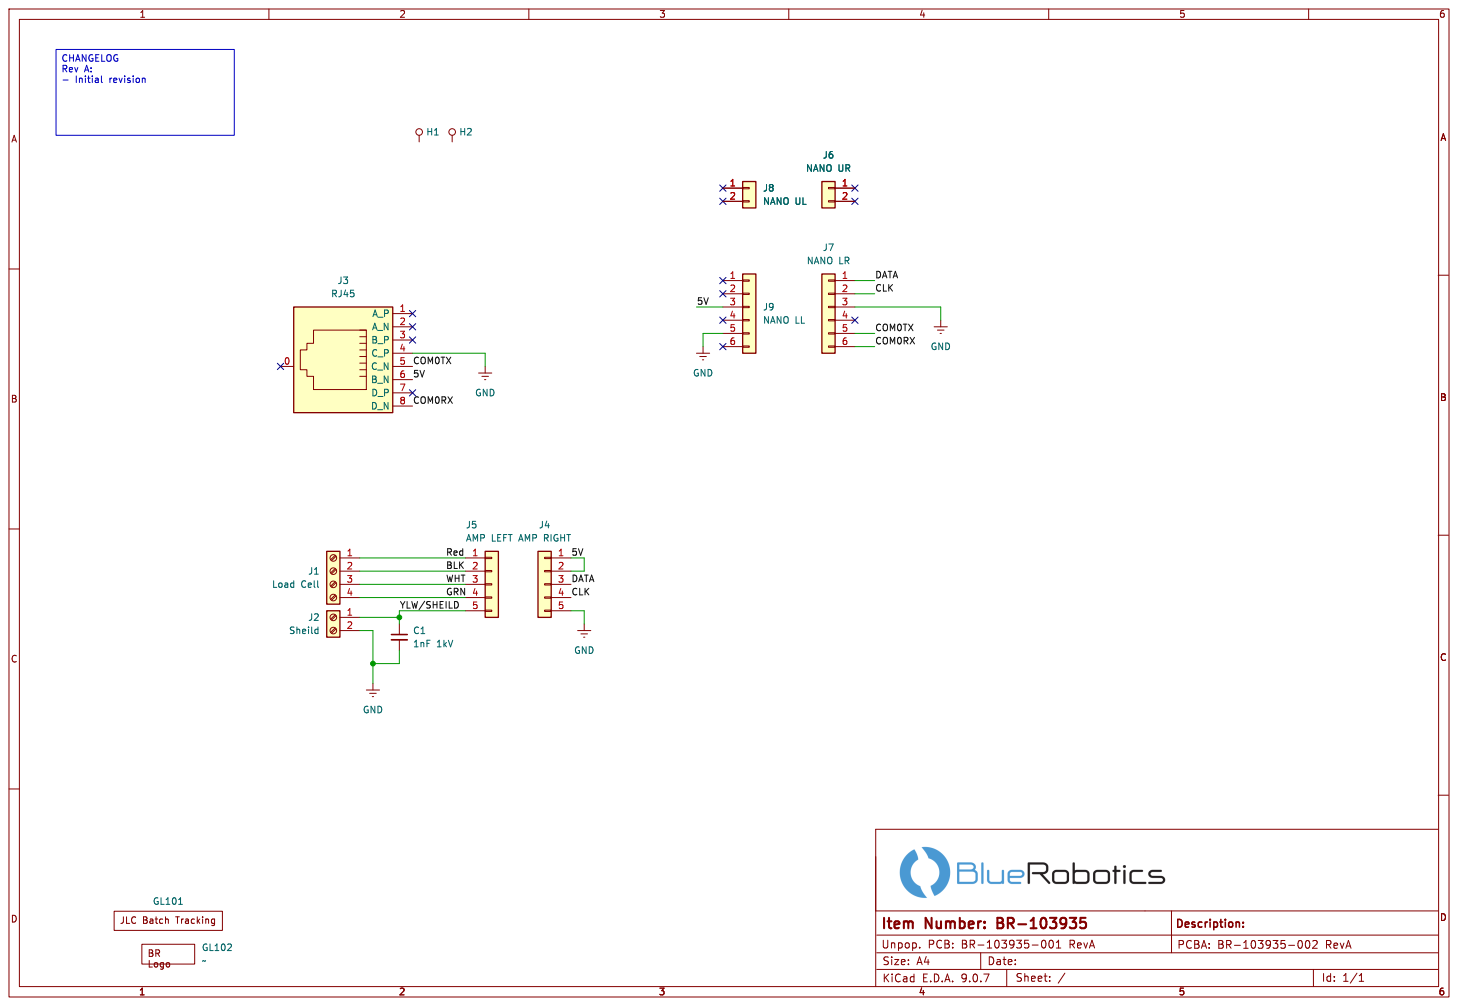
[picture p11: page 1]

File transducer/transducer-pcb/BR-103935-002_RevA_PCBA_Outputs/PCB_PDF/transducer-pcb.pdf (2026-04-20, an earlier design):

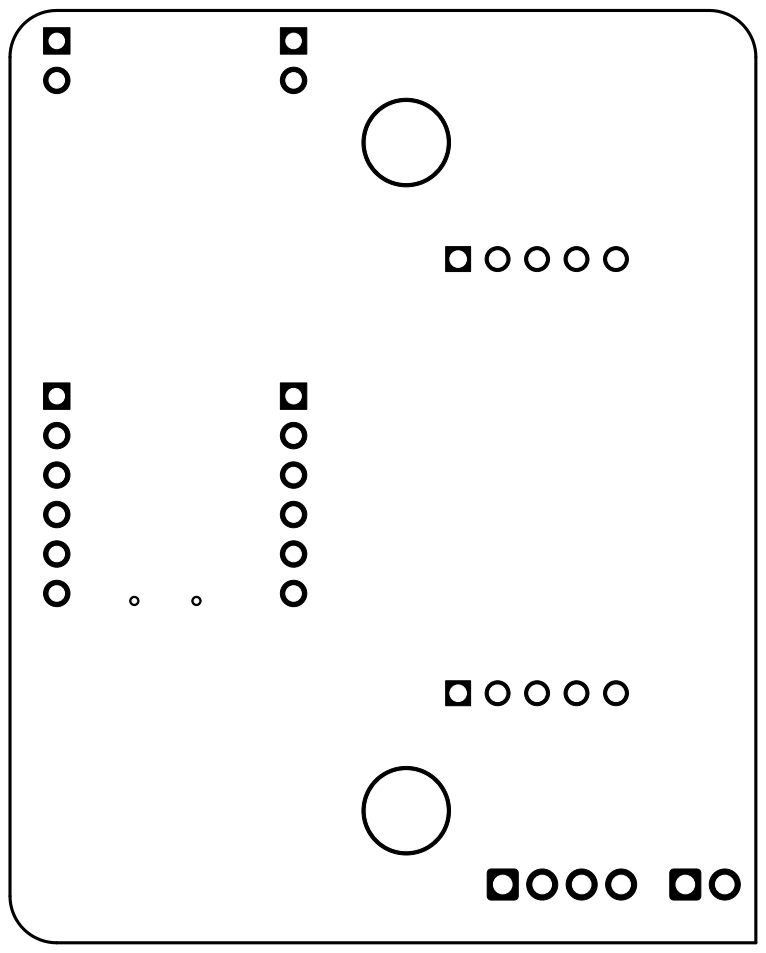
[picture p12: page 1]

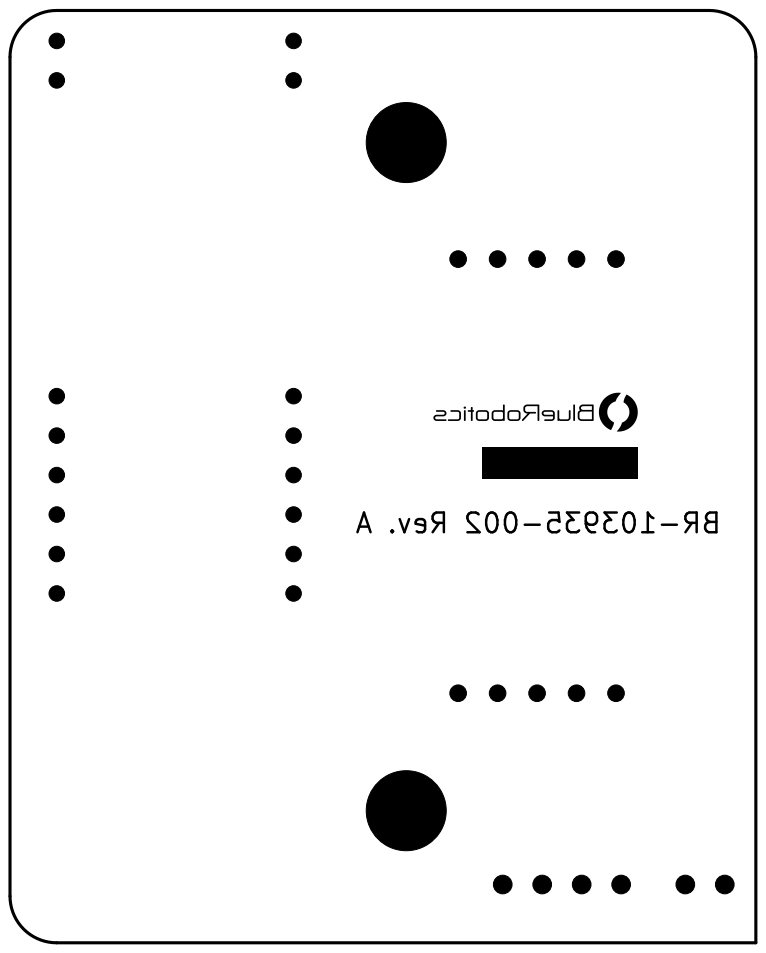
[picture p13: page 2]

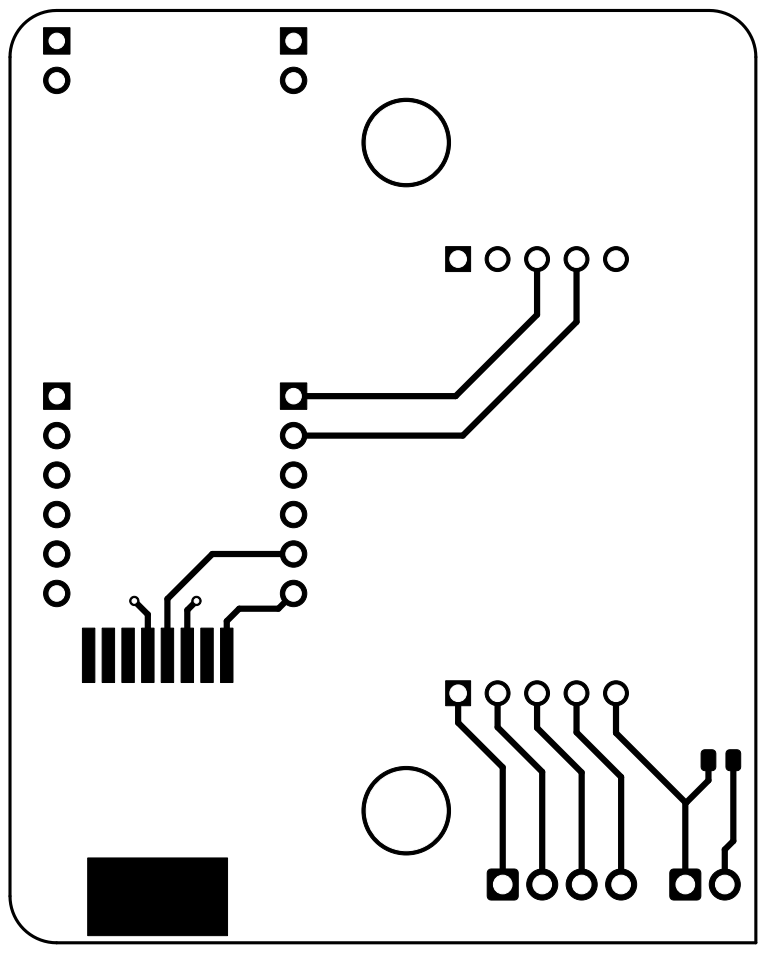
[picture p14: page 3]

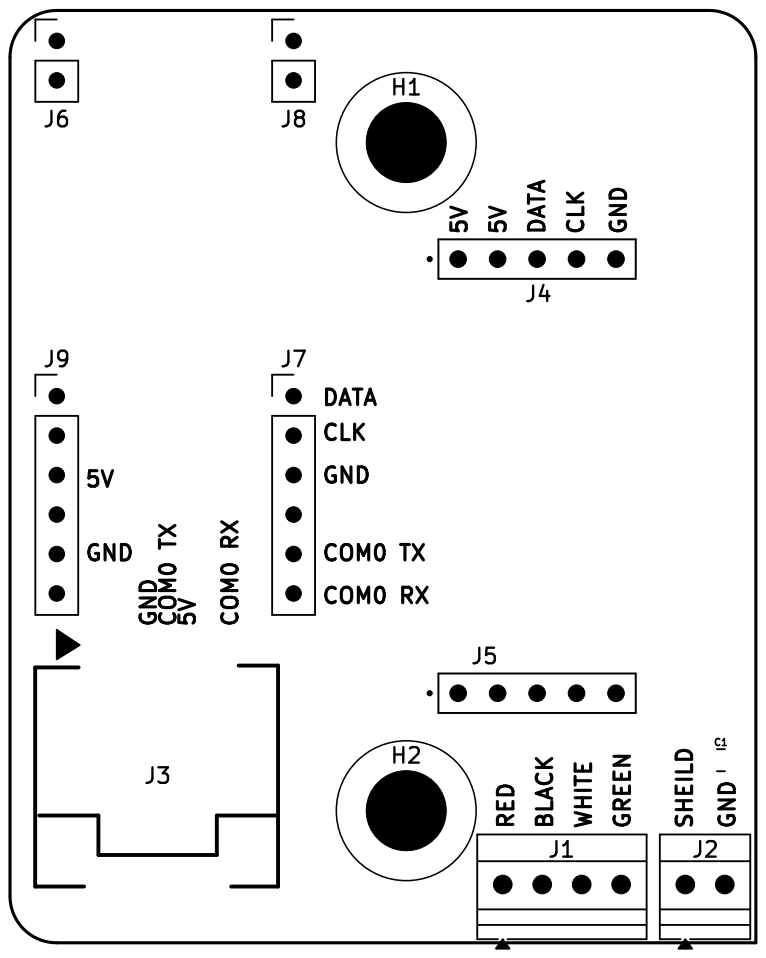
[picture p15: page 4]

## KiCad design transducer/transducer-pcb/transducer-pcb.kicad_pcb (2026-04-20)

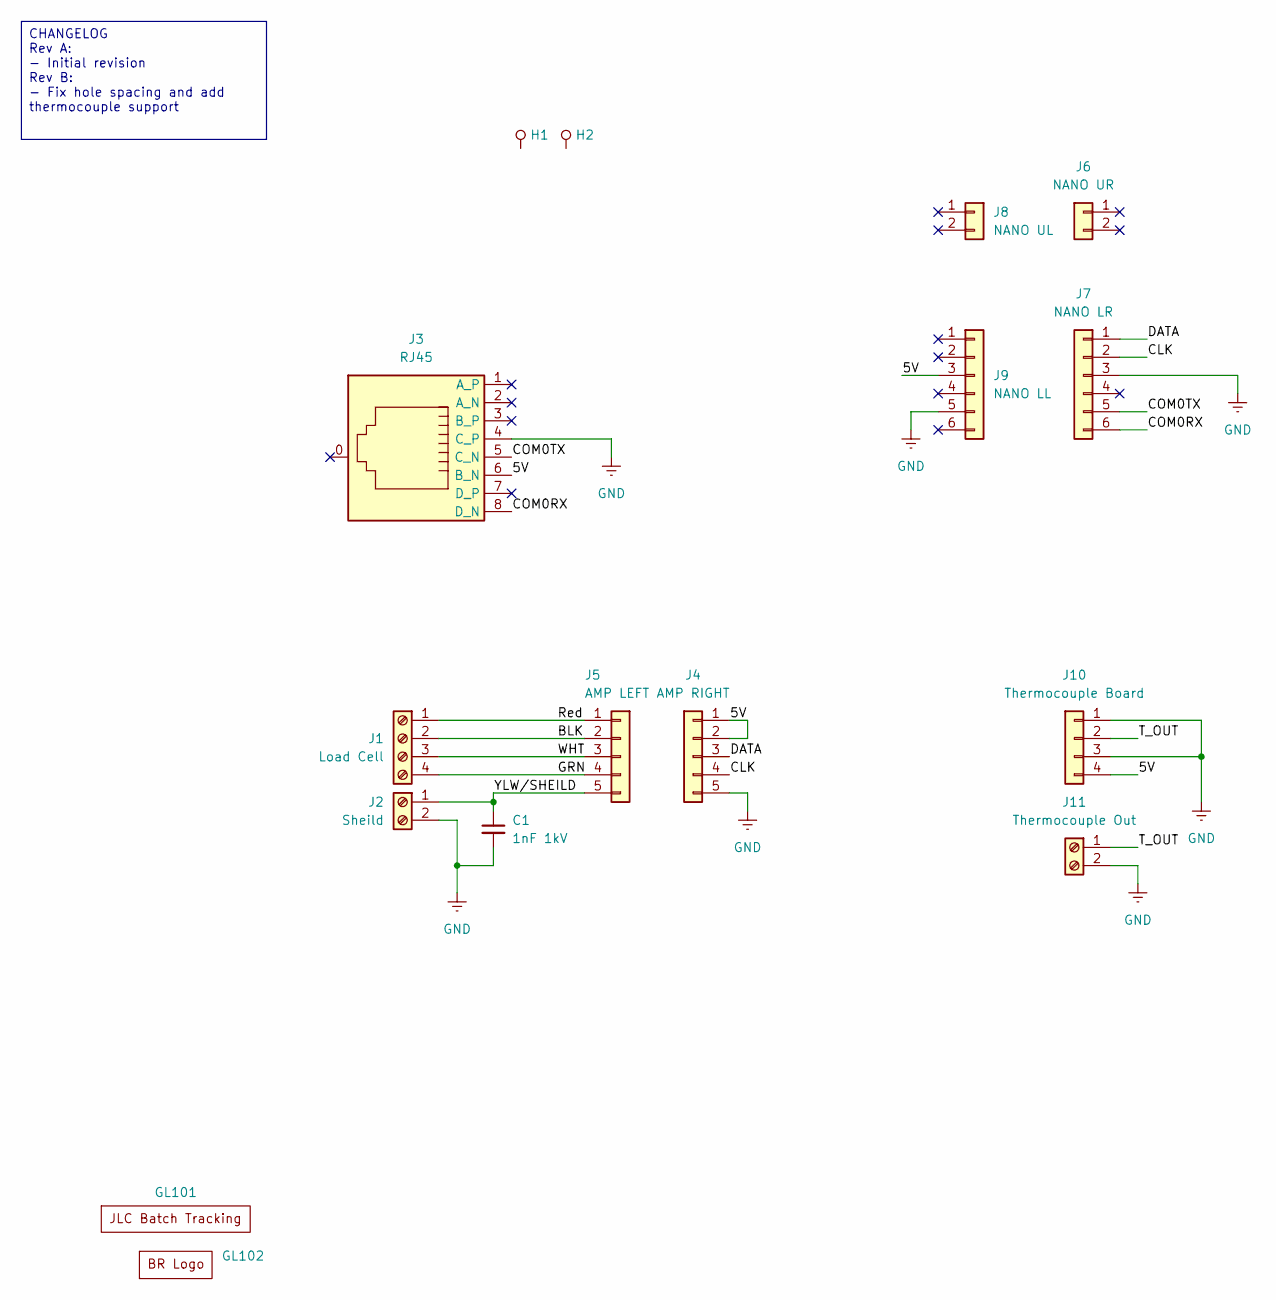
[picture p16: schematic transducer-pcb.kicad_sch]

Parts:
C1: 1nF 1kV; C_0805_2012Metric-minimized; Manufacturer Part Num 0805B102K102CT; JLCPCB Part Num C303890
GL101: JLC_Number
GL102: BR_Logo
H1, H2: Pressfit_5.15mm_hole; PressFit_5.15mm_hole
J1: Load Cell; DB125-2.54-4P-GN-S; Manufacturer Part Num DB125-2.54-4P-GN-S; JLCPCB Part Num C918122
J2: Sheild; KF128-2.54-2P; Manufacturer Part Num KF128-2.54-2P; JLCPCB Part Num C474920
J3: RJ45; RJ45-SMD_8P-P1.27_RC02015; Manufacturer Part Num RC02015; LCSC Part C708654
J4: AMP RIGHT; Pin_Header_1x5_2.54mm_Vertical; Manufacturer Part Num HB-PH3-25415PB2GOP; JLCPCB Part Num C6332198
J5: AMP LEFT; Pin_Header_1x5_2.54mm_Vertical; Manufacturer Part Num HB-PH3-25415PB2GOP; JLCPCB Part Num C6332198
J6: NANO UR; PinHeader_1x02_P2.54mm_Vertical; Manufacturer Part Num PZ254V-11-02P; JLCPCB Part Num C492401
J7: NANO LR; PinHeader_1x06_P2.54mm_Vertical; Manufacturer Part Num PZ2.54-1X6P-H25; JLCPCB Part Num C42431790
J8: NANO UL; PinHeader_1x02_P2.54mm_Vertical; Manufacturer Part Num PZ254V-11-02P; JLCPCB Part Num C492401
J9: NANO LL; PinHeader_1x06_P2.54mm_Vertical; Manufacturer Part Num PZ2.54-1X6P-H25; JLCPCB Part Num C42431790
J10: Thermocouple Board; Pin_Header_1x4_2.54mm_Vertical; Manufacturer Part Num PZ254V-11-04P; JLCPCB Part Num C5116483
J11: Thermocouple Out; KF128-2.54-2P; Manufacturer Part Num KF128-2.54-2P; JLCPCB Part Num C474920

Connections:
/5V: J3.6 (B_N), J4.1, J4.2, J9.3, J10.4
/BLK: J1.2, J5.2
/CLK: J4.4, J7.2
/COM0RX: J3.8 (D_N), J7.6
/COM0TX: J3.5 (C_N), J7.5
/DATA: J4.3, J7.1
/GRN: J1.4, J5.4
/Red: J1.1, J5.1
/T_OUT: J10.2, J11.1
/WHT: J1.3, J5.3
/YLW/SHEILD: C1.1, J2.1, J5.5
GND: C1.2, J2.2, J3.4 (C_P), J4.5, J7.3, J9.5, J10.1, J10.3, J11.2

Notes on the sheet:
CHANGELOG Rev A: - Initial revision Rev B: - Fix hole spacing and add thermocouple support

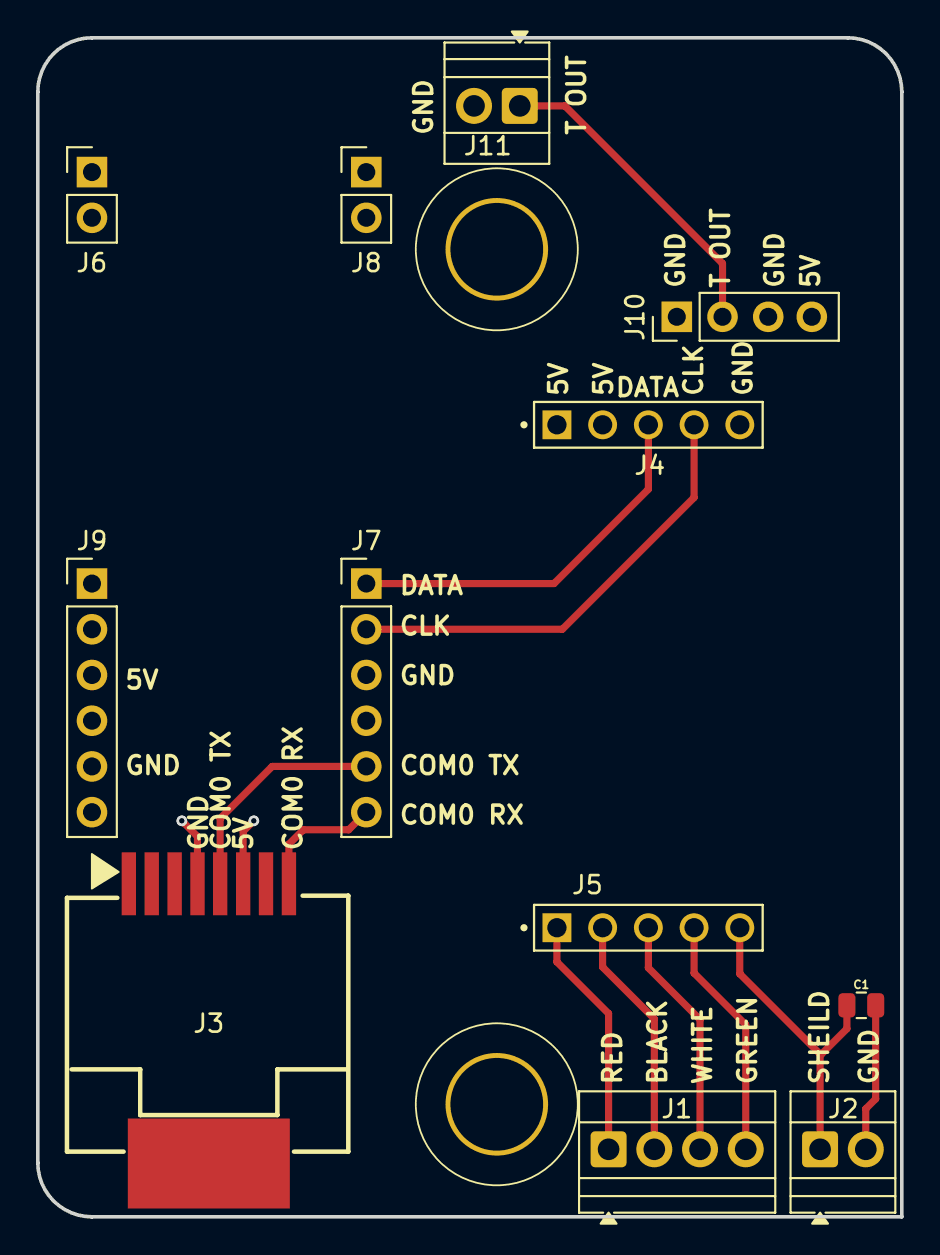
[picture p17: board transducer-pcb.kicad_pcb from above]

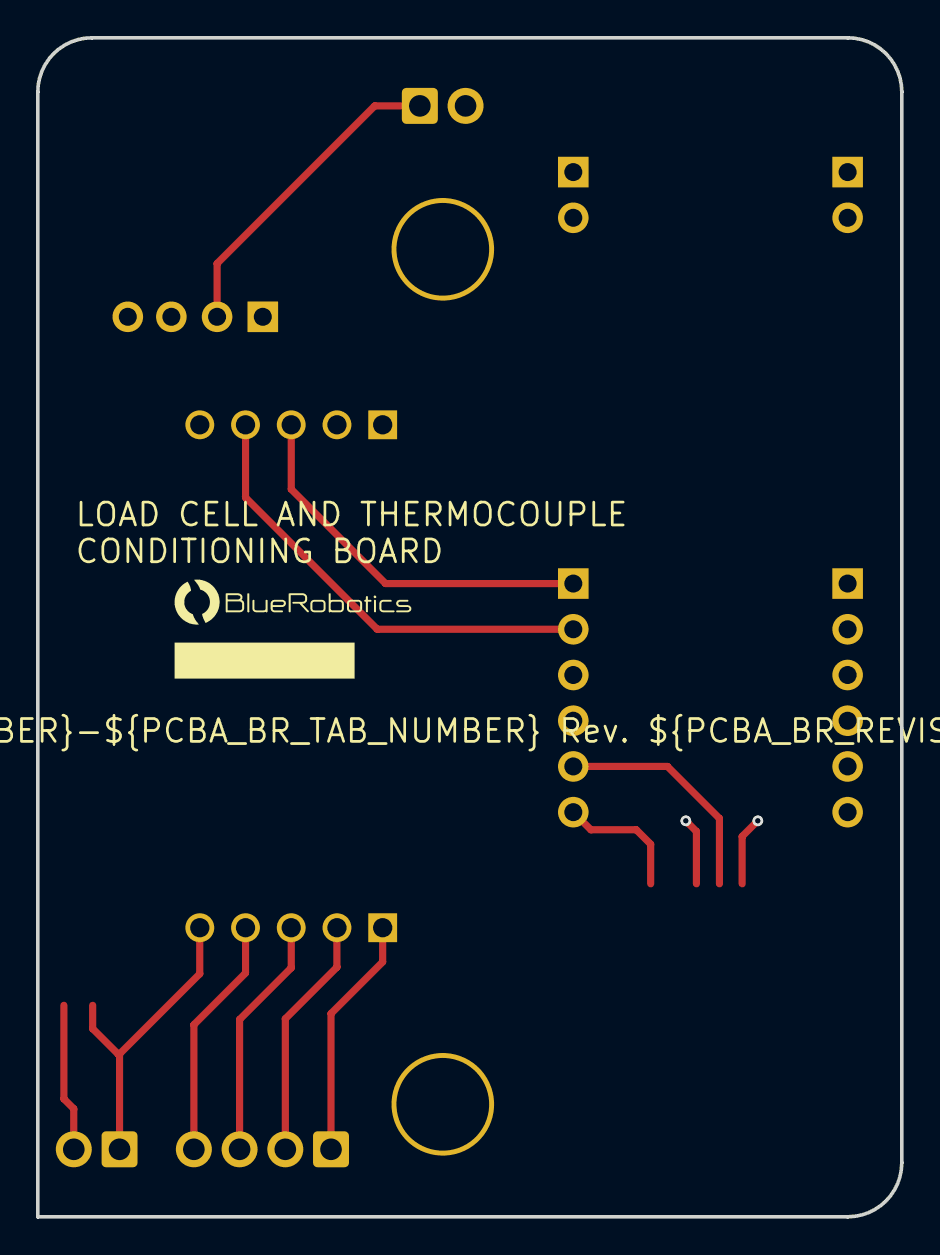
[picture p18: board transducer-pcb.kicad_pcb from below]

Board: 4 copper layers, 48.0 x 65.5 mm, 16 parts (2 on the bottom side), 12 nets.

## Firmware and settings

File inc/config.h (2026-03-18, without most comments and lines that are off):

#pragma once
#include "ClearCore.h"
#define DEVICE_NAME_UPPER               "PRESSBOI"  ///< Device name in uppercase for message prefixes
#define DEVICE_NAME_LOWER               "pressboi"  ///< Device name in lowercase for identifiers
#define LOCAL_PORT                      8888      ///< The UDP port this device listens on for incoming commands.
#define CLIENT_PORT                     6272      ///< The UDP port the GUI client listens on.
#define MAX_PACKET_LENGTH               1024      ///< Maximum size in bytes for a single UDP packet. Must be large enough for the longest telemetry string.
#define RX_QUEUE_SIZE                   32        ///< Number of incoming messages that can be buffered before processing.
#define TX_QUEUE_SIZE                   32        ///< Number of outgoing messages that can be buffered before sending.
#define MAX_MESSAGE_LENGTH              MAX_PACKET_LENGTH ///< Maximum size of a single message in the Rx/Tx queues.
#define TELEMETRY_INTERVAL_MS			100       ///< How often (in milliseconds) telemetry data is published to the GUI.
#define FIRMWARE_VERSION                "1.14.1"   ///< Pressboi firmware version
#define STATUS_MESSAGE_BUFFER_SIZE      256       ///< Standard buffer size for composing status and error messages.
#define PITCH_MM_PER_REV                5.0f      ///< Linear travel (in mm) of the press for one full motor revolution.
#define PULSES_PER_REV                  800       ///< Number of step pulses required for one full motor revolution (dependent on microstepping settings).
#define STEPS_PER_MM                    (PULSES_PER_REV / PITCH_MM_PER_REV)   ///< Calculated steps per millimeter for the press drive.
#define MAX_HOMING_DURATION_MS          100000    ///< Maximum time (in milliseconds) a homing operation is allowed to run before timing out.
#define MOTOR_A                         ConnectorM0 ///< Primary press motor.
#define MOTOR_B                         ConnectorM1 ///< Secondary, ganged press motor.
#define HOME_SENSOR_M0                  ConnectorDI7 ///< Motor A (M0) home sensor on DI7.
#define HOME_SENSOR_M1                  ConnectorDI6 ///< Motor B (M1) home sensor on DI6.
#define HOME_SENSOR_ACTIVE_STATE        true         ///< true = sensor outputs HIGH when triggered (active high).
#define HOME_SENSOR_FILTER_MS           2            ///< Debounce filter length in milliseconds for home sensors.
#define EWMA_ALPHA_TORQUE               0.2f      ///< Smoothing factor (alpha) for the EWMA filter on motor torque readings.
#define TORQUE_HLFB_AT_POSITION		-9999.0f  ///< Special value from ClearCore HLFB when a move is complete and the motor is at position.
#define MOTOR_DEFAULT_VEL_MAX_MMS           156.25f   ///< Default maximum velocity for motors in mm/s.
#define MOTOR_DEFAULT_ACCEL_MAX_MMSS        625.0f    ///< Default maximum acceleration for motors in mm/s^2.
#define MOTOR_DEFAULT_VEL_MAX_SPS           (int)(MOTOR_DEFAULT_VEL_MAX_MMS * STEPS_PER_MM) ///< Default max velocity in steps/sec, derived from mm/s.
#define MOTOR_DEFAULT_ACCEL_MAX_SPS2        (int)(MOTOR_DEFAULT_ACCEL_MAX_MMSS * STEPS_PER_MM) ///< Default max acceleration in steps/sec^2, derived from mm/s^2.
#define MOVE_START_TIMEOUT_MS           (250)     ///< Time (in ms) to wait for a move to start before flagging a motor error.
#define DEFAULT_TORQUE_LIMIT       80.0f     ///< Default torque limit (%) for general motor operations.
#define DEFAULT_TORQUE_OFFSET      -2.4f     ///< Default torque offset (%) to account for sensor bias or no-load friction.
#define HOMING_STROKE_MM           500.0f    ///< Maximum travel distance (mm) during a homing sequence.
#define HOMING_RAPID_VEL_MMS       5.0f      ///< Velocity (mm/s) for the initial high-speed search for the hard stop.
#define HOMING_TOUCH_VEL_MMS       1.0f      ///< Velocity (mm/s) for the final, slow-speed precise touch-off.
#define HOMING_BACKOFF_VEL_MMS     1.0f      ///< Velocity (mm/s) for backing off the hard stop.
#define HOMING_ACCEL_MMSS          100.0f    ///< Acceleration (mm/s^2) for all homing moves.
#define HOMING_SEARCH_TORQUE_PERCENT 10.0f   ///< Torque limit (%) used to detect the hard stop.
#define HOMING_BACKOFF_TORQUE_PERCENT 40.0f  ///< Higher torque limit (%) for the back-off move to prevent stalling.
#define HOMING_BACKOFF_MM          1.0f      ///< Distance (mm) to back off from the hard stop.
#define MOVE_DEFAULT_TORQUE_PERCENT         30        ///< Default torque limit (%) for moves.
#define MOVE_DEFAULT_VELOCITY_MMS           6.25f     ///< Default velocity (mm/s) for moves.
#define MOVE_DEFAULT_ACCEL_MMSS             62.5f     ///< Default acceleration (mm/s^2) for moves.
#define MOVE_DEFAULT_VELOCITY_SPS           (int)(MOVE_DEFAULT_VELOCITY_MMS * STEPS_PER_MM) ///< Default velocity in steps/sec.
#define MOVE_DEFAULT_ACCEL_SPS2             (int)(MOVE_DEFAULT_ACCEL_MMSS * STEPS_PER_MM)   ///< Default acceleration in steps/sec^2.
#define FORCE_SENSOR_ENABLED                true      ///< Enable/disable force sensor functionality. Set to false if no force transducer is connected.
#define FORCE_SENSOR_SCALE_FACTOR           -0.00023076f  ///< Default scale factor: kg = raw_adc × scale. Calibrated: -52000 raw = 12.0 kg → 1/-4333.33
#define FORCE_SENSOR_OFFSET_KG              6.5f     ///< Default offset (kg) to add to all force readings for calibration.
#define MACHINE_STRAIN_COEFF_X4            -4617.6757f     ///< x^4 coefficient (force in kg, displacement in millimeters)
#define MACHINE_STRAIN_COEFF_X3             6910.4430f     ///< x^3 coefficient
#define MACHINE_STRAIN_COEFF_X2            -1585.3214f     ///< x^2 coefficient
#define MACHINE_STRAIN_COEFF_X1             320.1528f      ///< x coefficient
#define MACHINE_STRAIN_COEFF_C              -0.2376f       ///< Constant term
#define MACHINE_STRAIN_MAX_DEFLECTION_MM     5.0f          ///< Max expected machine flex deflection used for inverse lookup (can expand to 4x this)
#define MACHINE_STRAIN_CONTACT_FORCE_KG      3.0f          ///< Force threshold to declare contact and start flex compensation
#define RETRACT_DEFAULT_SPEED_MMS           25.0f          ///< Default retract speed when none specified
#define FORCE_SENSOR_MIN_KG                 -10.0f    ///< Minimum valid force reading (kg). Below this triggers an error.
#define FORCE_SENSOR_MAX_KG                 1200.0f   ///< Maximum expected force (kg).
#define FORCE_SENSOR_MAX_SAFETY_FACTOR      1.2f      ///< Safety factor for maximum force (1.2x = 20% over max).
#define FORCE_SENSOR_MAX_LIMIT_KG           (FORCE_SENSOR_MAX_KG * FORCE_SENSOR_MAX_SAFETY_FACTOR) ///< Calculated max limit (1440 kg).
#define FORCE_SENSOR_TIMEOUT_MS             1000      ///< Time (ms) without readings before sensor is considered disconnected.
#define WATCHDOG_ENABLED                    true      ///< Enable/disable watchdog timer. When enabled, system must call safety check regularly or motors will be disabled.
#define WATCHDOG_TIMEOUT_MS                 256       ///< Watchdog timeout period in milliseconds. System will reset if not fed within this time.
#define WATCHDOG_RECOVERY_FLAG              0xDEADBEEF ///< Magic number written to backup register to indicate watchdog recovery.
#define WD_BREADCRUMB_SAFETY_CHECK          0x01      ///< Watchdog timeout in safety check
#define WD_BREADCRUMB_COMMS_UPDATE          0x02      ///< Watchdog timeout in communications update
#define WD_BREADCRUMB_RX_DEQUEUE            0x03      ///< Watchdog timeout in RX message dequeue
#define WD_BREADCRUMB_UPDATE_STATE          0x04      ///< Watchdog timeout in state machine update
#define WD_BREADCRUMB_FORCE_UPDATE          0x05      ///< Watchdog timeout in force sensor update
#define WD_BREADCRUMB_MOTOR_UPDATE          0x06      ///< Watchdog timeout in motor update
#define WD_BREADCRUMB_TELEMETRY             0x07      ///< Watchdog timeout in telemetry publishing
#define WD_BREADCRUMB_UDP_PROCESS           0x08      ///< Watchdog timeout in UDP packet processing
#define WD_BREADCRUMB_USB_PROCESS           0x09      ///< Watchdog timeout in USB serial processing
#define WD_BREADCRUMB_TX_QUEUE              0x0A      ///< Watchdog timeout in TX queue processing
#define WD_BREADCRUMB_UDP_SEND              0x0B      ///< Watchdog timeout in UDP packet send
#define WD_BREADCRUMB_NETWORK_REFRESH       0x0C      ///< Watchdog timeout in network packet refresh
#define WD_BREADCRUMB_USB_SEND              0x0D      ///< Watchdog timeout in USB send operation
#define WD_BREADCRUMB_USB_RECONNECT         0x0E      ///< Watchdog timeout in USB reconnection handling
#define WD_BREADCRUMB_USB_RECOVERY          0x0F      ///< Watchdog timeout in USB recovery operation
#define WD_BREADCRUMB_REPORT_EVENT          0x10      ///< Watchdog timeout in reportEvent (start)
#define WD_BREADCRUMB_ENQUEUE_TX            0x11      ///< Watchdog timeout in enqueueTx
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

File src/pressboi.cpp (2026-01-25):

/**
 * @file pressboi.cpp
 * @author Eldin Miller-Stead
 * @date November 3, 2025
 * @brief Implements the master controller for the Pressboi press system.
 *
 * @details This file provides the concrete implementation for the `Pressboi` class
 * as defined in `pressboi.h`. It contains the logic for the main application loop,
 * command dispatch, state management, and the orchestration of the motor controller.
 * The program's entry point, `main()`, is also located here.
 */

//==================================================================================================
// --- Includes ---
//==================================================================================================
#include "pressboi.h"
#include "commands.h"
#include "variables.h"
#include "events.h"
#include "error_log.h"
#include "NvmManager.h"
#include <cstring>
#include <cstdlib>
#include <sam.h>  // For watchdog timer (WDT) register access

//==================================================================================================
// --- Global Telemetry Data ---
//==================================================================================================
TelemetryData g_telemetry;

//==================================================================================================
// --- Watchdog Recovery Flag and Breadcrumb (Survives Reset) ---
//==================================================================================================
#if WATCHDOG_ENABLED
// Place in .noinit section so it survives reset but is cleared on power-up
__attribute__((section(".noinit"))) volatile uint32_t g_watchdogRecoveryFlag;
__attribute__((section(".noinit"))) volatile uint32_t g_watchdogBreadcrumb;
// Captured at boot time for accurate reporting (breadcrumb changes during normal operation)
static uint32_t g_crashTimeBreadcrumb = 0;
// Breadcrumb codes are now defined in config.h
#endif

//==================================================================================================
// --- External sendMessage function for events and telemetry ---
//==================================================================================================
extern Pressboi pressboi;

void sendMessage(const char* msg) {
    // Events and telemetry already have their prefixes, so send directly
    // Always queue messages - they will be sent to network (if GUI discovered) and USB
    // If GUI not discovered, use dummy IP - processTxQueue will still mirror to USB
    bool guiDiscovered = pressboi.m_comms.isGuiDiscovered();
    IpAddress targetIp = guiDiscovered ? pressboi.m_comms.getGuiIp() : IpAddress(0, 0, 0, 0);
    uint16_t targetPort = guiDiscovered ? pressboi.m_comms.getGuiPort() : 0;
    
    pressboi.m_comms.enqueueTx(msg, targetIp, targetPort);
}

//==================================================================================================
// --- Watchdog Early Warning Interrupt Handler ---
//==================================================================================================
#if WATCHDOG_ENABLED
/**
 * @brief Watchdog early warning interrupt handler.
 * @details This interrupt is triggered before the watchdog causes a system reset,
 * giving us a chance to safely disable motors and float all outputs. Sets a persistent
 * flag so the system knows it recovered from a watchdog reset on the next boot.
 */
extern "C" void WDT_Handler(void) {
    // Clear the early warning interrupt flag
    WDT->INTFLAG.reg = WDT_INTFLAG_EW;
    
    // Immediately disable all motors to prevent damage
    MOTOR_A.EnableRequest(false);
    MOTOR_B.EnableRequest(false);
    
    // Turn on the LED to indicate watchdog trigger (red/error state)
    ConnectorLed.Mode(Connector::OUTPUT_DIGITAL);
    ConnectorLed.State(true);
    
    // Set recovery flag in .noinit memory (survives reset)
    g_watchdogRecoveryFlag = WATCHDOG_RECOVERY_FLAG;
    
    // Blink the LED rapidly to make it obvious something went wrong
    for (int i = 0; i < 5; i++) {
        ConnectorLed.State(true);
        for (volatile int d = 0; d < 5000; d++);  // Short delay
        ConnectorLed.State(false);
        for (volatile int d = 0; d < 5000; d++);  // Short delay
    }
    
    // System will reset shortly after this ISR completes
    // On next boot, setup() will detect the recovery flag and enter STATE_RECOVERED
}
#endif

//==================================================================================================
// --- Pressboi Class Implementation ---
//==================================================================================================

/**
 * @brief Constructs the Pressboi master controller.
 */
Pressboi::Pressboi() :
    m_comms(),
    m_motor(&MOTOR_A, &MOTOR_B, this)
{
    m_mainState = STATE_STANDBY;
    m_lastTelemetryTime = 0;
    m_resetStartTime = 0;
    m_faultGracePeriodEnd = 0;
    m_homingPending = false;
    m_homingDelayStart = 0;
    
    // Initialize telemetry
    telemetry_init(&g_telemetry);
}

/**
 * @brief Initializes all hardware and sub-controllers for the entire system.
 */
void Pressboi::setup() {
    // IMPORTANT: Capture the crash-time breadcrumb BEFORE overwriting it!
    // This must happen at the very start of setup() to get the true crash location
    // from the previous boot (if it was a watchdog reset).
    #if WATCHDOG_ENABLED
    g_crashTimeBreadcrumb = g_watchdogBreadcrumb;  // Capture before overwrite
    g_watchdogBreadcrumb = WD_BREADCRUMB_SETUP;    // Now mark as in setup phase
    #endif
    
    // Configure all motors for step and direction control mode.
    #if WATCHDOG_ENABLED
    g_watchdogBreadcrumb = WD_BREADCRUMB_SETUP_MOTOR_MODE;
    #endif
    MotorMgr.MotorModeSet(MotorManager::MOTOR_ALL, Connector::CPM_MODE_STEP_AND_DIR);

    // Log firmware startup
    g_errorLog.log(LOG_INFO, "=== FIRMWARE STARTUP ===");
    g_errorLog.logf(LOG_INFO, "Firmware version: %s", FIRMWARE_VERSION);
    
    // Initialize comms first (can take time for network setup)
    #if WATCHDOG_ENABLED
    g_watchdogBreadcrumb = WD_BREADCRUMB_SETUP_COMMS;
    #endif
    m_comms.setup();
    
    #if WATCHDOG_ENABLED
    g_watchdogBreadcrumb = WD_BREADCRUMB_SETUP_MOTOR;
    #endif
    m_motor.setup();
    
    #if WATCHDOG_ENABLED
    g_watchdogBreadcrumb = WD_BREADCRUMB_SETUP_FORCE;
    #endif
    m_forceSensor.setup();
    
#if WATCHDOG_ENABLED
    // Initialize watchdog AFTER comms setup to avoid timeout during network initialization
    g_watchdogBreadcrumb = WD_BREADCRUMB_SETUP_WD_RECOVERY;
    handleWatchdogRecovery();
    
    g_watchdogBreadcrumb = WD_BREADCRUMB_SETUP_WD_INIT;
    initializeWatchdog();
    
    // Feed watchdog immediately after enabling to give maximum time for startup messages
    feedWatchdog();
#endif
    
    // Only report normal startup if not in RECOVERED state
    if (m_mainState != STATE_RECOVERED) {
        m_comms.reportEvent(STATUS_PREFIX_INFO, "Pressboi system setup complete. All components initialized.");
        
        #if WATCHDOG_ENABLED
        feedWatchdog();  // Feed after each message during startup
        #endif
        
        g_errorLog.log(LOG_INFO, "Setup complete - normal boot");
        
        // Auto-home will be initiated after a short delay in the main loop
        // This prevents watchdog timeout during the busy startup/reconnection period
        if (m_motor.getHomeOnBoot()) {
            m_homingPending = true;  // Flag to initiate homing after delay
            m_homingDelayStart = 0;  // Will be set in first loop iteration
            m_comms.reportEvent(STATUS_PREFIX_INFO, "Auto-homing enabled. Will initiate after startup stabilization...");
        } else {
            m_comms.reportEvent(STATUS_PREFIX_INFO, "Auto-homing disabled. System ready in standby mode.");
        }
        
        #if WATCHDOG_ENABLED
        feedWatchdog();  // Feed after startup messages
        #endif
    } else {
        g_errorLog.log(LOG_ERROR, "Setup complete - RECOVERED from watchdog");
    }
}

/**
 * @brief The main execution loop for the Pressboi system.
 */
void Pressboi::loop() {
    // 1. Perform safety checks and feed the watchdog timer.
    #if WATCHDOG_ENABLED
    g_watchdogBreadcrumb = WD_BREADCRUMB_SAFETY_CHECK;
    #endif
    performSafetyCheck();

    // 2. Process all incoming/outgoing communication queues.
    #if WATCHDOG_ENABLED
    g_watchdogBreadcrumb = WD_BREADCRUMB_COMMS_UPDATE;
    #endif
    m_comms.update();

    // 3. Check for and handle one new command from the receive queue.
    #if WATCHDOG_ENABLED
    g_watchdogBreadcrumb = WD_BREADCRUMB_RX_DEQUEUE;
    #endif
    Message msg;
    if (m_comms.dequeueRx(msg)) {
        dispatchCommand(msg);
    }

    // 4. Update force sensor readings.
    #if WATCHDOG_ENABLED
    g_watchdogBreadcrumb = WD_BREADCRUMB_FORCE_UPDATE;
    #endif
    m_forceSensor.update();

    // 5. Update the main state machine and all sub-controllers.
    #if WATCHDOG_ENABLED
    g_watchdogBreadcrumb = WD_BREADCRUMB_UPDATE_STATE;
    #endif
    updateState();

    // 6. Handle time-based periodic tasks.
    uint32_t now = Milliseconds();
	
    // Always send telemetry (for both network and USB)
    if (now - m_lastTelemetryTime >= TELEMETRY_INTERVAL_MS) {
        // Skip telemetry if we're too close to discovery time (network may not be stable yet)
        static uint32_t discoveryTime = 0;
        static bool wasDiscovered = false;
        if (!wasDiscovered && m_comms.isGuiDiscovered()) {
            discoveryTime = now;
            wasDiscovered = true;
        }
        if (!m_comms.isGuiDiscovered()) {
            wasDiscovered = false;
        }
        
        // Wait at least 500ms after GUI discovery before sending (only affects network, USB always works)
        bool skipForNetworkStability = m_comms.isGuiDiscovered() && (now - discoveryTime < 500);
        
        if (!skipForNetworkStability) {
            #if WATCHDOG_ENABLED
            g_watchdogBreadcrumb = WD_BREADCRUMB_TELEMETRY;
            #endif
            m_lastTelemetryTime = now;
            publishTelemetry();
        } else {
            m_lastTelemetryTime = now; // Reset timer so we don't immediately spam after 500ms
        }
    }
    
    // Handle delayed auto-homing on boot (prevents watchdog timeout during busy startup)
    if (m_homingPending && m_mainState == STATE_STANDBY) {
        // Initialize delay timer on first iteration
        if (m_homingDelayStart == 0) {
            m_homingDelayStart = now;
        }
        
        // Wait 2 seconds after startup before initiating homing
        // This allows USB/network to stabilize and message queues to clear
        if (now - m_homingDelayStart > 2000) {
            m_homingPending = false;
            m_comms.reportEvent(STATUS_PREFIX_INFO, "Initiating delayed auto-home sequence...");
            m_motor.handleCommand(CMD_HOME, "");
        }
    }
    
    // If we're in RECOVERED state and GUI just connected, resend the recovery message with breadcrumb
    static bool recovery_msg_sent = false;
    if (m_mainState == STATE_RECOVERED && m_comms.isGuiDiscovered() && !recovery_msg_sent) {
        recovery_msg_sent = true;
        
        // Build recovery message with breadcrumb captured at boot time
        // (not g_watchdogBreadcrumb which changes during normal operation)
        char recoveryMsg[128];
        const char* breadcrumb_name = "UNKNOWN";
        switch (g_crashTimeBreadcrumb) {
            case WD_BREADCRUMB_SAFETY_CHECK: breadcrumb_name = "SAFETY_CHECK"; break;
            case WD_BREADCRUMB_COMMS_UPDATE: breadcrumb_name = "COMMS_UPDATE"; break;
            case WD_BREADCRUMB_RX_DEQUEUE: breadcrumb_name = "RX_DEQUEUE"; break;
            case WD_BREADCRUMB_UPDATE_STATE: breadcrumb_name = "UPDATE_STATE"; break;
            case WD_BREADCRUMB_FORCE_UPDATE: breadcrumb_name = "FORCE_UPDATE"; break;
            case WD_BREADCRUMB_MOTOR_UPDATE: breadcrumb_name = "MOTOR_UPDATE"; break;
            case WD_BREADCRUMB_TELEMETRY: breadcrumb_name = "TELEMETRY"; break;
            case WD_BREADCRUMB_UDP_PROCESS: breadcrumb_name = "UDP_PROCESS"; break;
            case WD_BREADCRUMB_USB_PROCESS: breadcrumb_name = "USB_PROCESS"; break;
            case WD_BREADCRUMB_TX_QUEUE: breadcrumb_name = "TX_QUEUE"; break;
            case WD_BREADCRUMB_UDP_SEND: breadcrumb_name = "UDP_SEND"; break;
            case WD_BREADCRUMB_NETWORK_REFRESH: breadcrumb_name = "NETWORK_REFRESH"; break;
            case WD_BREADCRUMB_USB_SEND: breadcrumb_name = "USB_SEND"; break;
            case WD_BREADCRUMB_USB_RECONNECT: breadcrumb_name = "USB_RECONNECT"; break;
            case WD_BREADCRUMB_USB_RECOVERY: breadcrumb_name = "USB_RECOVERY"; break;
            case WD_BREADCRUMB_REPORT_EVENT: breadcrumb_name = "REPORT_EVENT"; break;
            case WD_BREADCRUMB_ENQUEUE_TX: breadcrumb_name = "ENQUEUE_TX"; break;
            case WD_BREADCRUMB_MOTOR_IS_FAULT: breadcrumb_name = "MOTOR_IS_FAULT"; break;
            case WD_BREADCRUMB_MOTOR_STATE_SWITCH: breadcrumb_name = "MOTOR_STATE_SWITCH"; break;
            case WD_BREADCRUMB_PROCESS_TX_QUEUE: breadcrumb_name = "PROCESS_TX_QUEUE"; break;
            case WD_BREADCRUMB_TX_QUEUE_DEQUEUE: breadcrumb_name = "TX_QUEUE_DEQUEUE"; break;
            case WD_BREADCRUMB_TX_QUEUE_UDP: breadcrumb_name = "TX_QUEUE_UDP"; break;
            case WD_BREADCRUMB_TX_QUEUE_USB: breadcrumb_name = "TX_QUEUE_USB"; break;
            case WD_BREADCRUMB_DISPATCH_CMD: breadcrumb_name = "DISPATCH_CMD"; break;
            case WD_BREADCRUMB_PARSE_CMD: breadcrumb_name = "PARSE_CMD"; break;
            case WD_BREADCRUMB_MOTOR_FAULT_REPORT: breadcrumb_name = "MOTOR_FAULT_REPORT"; break;
            case WD_BREADCRUMB_STATE_BUSY_CHECK: breadcrumb_name = "STATE_BUSY_CHECK"; break;
            case WD_BREADCRUMB_UDP_PACKET_READ: breadcrumb_name = "UDP_PACKET_READ"; break;
            case WD_BREADCRUMB_RX_ENQUEUE: breadcrumb_name = "RX_ENQUEUE"; break;
            case WD_BREADCRUMB_USB_AVAILABLE: breadcrumb_name = "USB_AVAILABLE"; break;
            case WD_BREADCRUMB_USB_READ: breadcrumb_name = "USB_READ"; break;
            case WD_BREADCRUMB_NETWORK_INPUT: breadcrumb_name = "NETWORK_INPUT"; break;
            case WD_BREADCRUMB_LWIP_INPUT: breadcrumb_name = "LWIP_INPUT"; break;
            case WD_BREADCRUMB_LWIP_TIMEOUT: breadcrumb_name = "LWIP_TIMEOUT"; break;
            case WD_BREADCRUMB_SETUP: breadcrumb_name = "SETUP"; break;
            case WD_BREADCRUMB_SETUP_MOTOR_MODE: breadcrumb_name = "SETUP_MOTOR_MODE"; break;
            case WD_BREADCRUMB_SETUP_COMMS: breadcrumb_name = "SETUP_COMMS"; break;
            case WD_BREADCRUMB_SETUP_MOTOR: breadcrumb_name = "SETUP_MOTOR"; break;
            case WD_BREADCRUMB_SETUP_FORCE: breadcrumb_name = "SETUP_FORCE"; break;
            case WD_BREADCRUMB_SETUP_WD_RECOVERY: breadcrumb_name = "SETUP_WD_RECOVERY"; break;
            case WD_BREADCRUMB_SETUP_WD_INIT: breadcrumb_name = "SETUP_WD_INIT"; break;
            case WD_BREADCRUMB_SETUP_USB: breadcrumb_name = "SETUP_USB"; break;
            case WD_BREADCRUMB_SETUP_ETHERNET: breadcrumb_name = "SETUP_ETHERNET"; break;
            case WD_BREADCRUMB_SETUP_DHCP: breadcrumb_name = "SETUP_DHCP"; break;
            case WD_BREADCRUMB_SETUP_LINK_WAIT: breadcrumb_name = "SETUP_LINK_WAIT"; break;
        }
        snprintf(recoveryMsg, sizeof(recoveryMsg), "Watchdog timeout in %s - main loop blocked >256ms. Motors disabled. Send RESET to clear.", breadcrumb_name);
        reportEvent(STATUS_PREFIX_RECOVERY, recoveryMsg);
    }
    
    // Reset the flag when leaving RECOVERED state
    if (m_mainState != STATE_RECOVERED && recovery_msg_sent) {
        recovery_msg_sent = false;
    }
}

//==================================================================================================
// --- Private Methods: State, Command, and Telemetry Handling ---
//==================================================================================================

/**
 * @brief Performs safety checks and feeds the watchdog timer.
 */
void Pressboi::performSafetyCheck() {
#if WATCHDOG_ENABLED
    feedWatchdog();
    
    // Note: Motor fault detection is handled in updateState() as part of the normal state machine
    // This function focuses on feeding the watchdog and can be extended with additional
    // hardware-level safety checks if needed (e.g., force sensor limits, temperature monitoring)
#endif
}

/**
 * @brief Updates the main system state and the state machines of all sub-controllers.
 */
void Pressboi::updateState() {
    // First, update the state of the motor controller
    #if WATCHDOG_ENABLED
    g_watchdogBreadcrumb = WD_BREADCRUMB_MOTOR_UPDATE;
    #endif
    m_motor.updateState();

    // Now, update the main Pressboi state based on the motor controller state.
    #if WATCHDOG_ENABLED
    g_watchdogBreadcrumb = WD_BREADCRUMB_UPDATE_STATE;
    #endif
    #if WATCHDOG_ENABLED
    g_watchdogBreadcrumb = WD_BREADCRUMB_MOTOR_STATE_SWITCH;
    #endif
    switch (m_mainState) {
        case STATE_STANDBY:
        case STATE_BUSY: {
            // In normal operation, constantly monitor for faults.
            // Skip fault detection during grace period (after clearing faults) to prevent false alarms
            uint32_t now = Milliseconds();
            bool inGracePeriod = (now < m_faultGracePeriodEnd);
            
            #if WATCHDOG_ENABLED
            g_watchdogBreadcrumb = WD_BREADCRUMB_MOTOR_IS_FAULT;
            #endif
            if (!inGracePeriod && m_motor.isInFault()) {
                #if WATCHDOG_ENABLED
                g_watchdogBreadcrumb = WD_BREADCRUMB_MOTOR_FAULT_REPORT;
                #endif
                m_mainState = STATE_ERROR;
                g_errorLog.log(LOG_ERROR, "Motor fault detected -> ERROR state");
                reportEvent(STATUS_PREFIX_ERROR, "Motor fault detected. System entering ERROR state. Use CLEAR_ERRORS to reset.");
                break;
            }

            // If no faults, update the state based on whether motor is busy.
            #if WATCHDOG_ENABLED
            g_watchdogBreadcrumb = WD_BREADCRUMB_STATE_BUSY_CHECK;
            #endif
            MainState newState = m_motor.isBusy() ? STATE_BUSY : STATE_STANDBY;
            if (newState != m_mainState) {
                g_errorLog.logf(LOG_DEBUG, "State: %s -> %s", 
                    (m_mainState == STATE_STANDBY) ? "STANDBY" : "BUSY",
                    (newState == STATE_STANDBY) ? "STANDBY" : "BUSY");
            }
            m_mainState = newState;
            break;
        }

        case STATE_CLEARING_ERRORS: {
            // Wait for motor controller to finish its reset sequence.
            if (!m_motor.isBusy()) {
                // Now it's safe to cycle motor power.
                m_motor.disable();
                Delay_ms(10);
                m_motor.enable();

                // Recovery is complete.
                m_mainState = STATE_STANDBY;
                reportEvent(STATUS_PREFIX_DONE, "CLEAR_ERRORS complete. System is in STANDBY state.");
            }
            break;
        }

        case STATE_RESETTING: {
            // Non-blocking reset with phased motor enable
            uint32_t now = Milliseconds();
            
            // Phase 1: Wait 100ms after disable before re-enabling
            if (now - m_resetStartTime < 100) {
                break;  // Still waiting for delay
            }
            
            // Phase 2: Start motor enable (only once, when enable state is IDLE)
            if (m_motor.getEnableState() == ENABLE_IDLE) {
                // Clear any motor faults before re-enabling
                MOTOR_A.ClearAlerts();
                MOTOR_B.ClearAlerts();
                
                // Start non-blocking motor enable
                m_motor.enable();
                break;  // Wait for next iteration to check enable status
            }
            
            // Phase 3: Wait for enable to complete (non-blocking check)
            m_motor.updateEnableState();
            if (!m_motor.isEnableComplete()) {
                break;  // Still waiting for motors to enable
            }
            
            // Phase 4: Enable complete - finish reset
            // Set grace period to ignore faults for 500ms after clearing
            // This prevents false alarms as the motor driver status stabilizes
            m_faultGracePeriodEnd = now + 500;
            
            // Reset complete, transition to standby
            standby();
            reportEvent(STATUS_PREFIX_DONE, "reset");
            m_mainState = STATE_STANDBY;
            break;
        }

        case STATE_ERROR:
        case STATE_DISABLED:
        case STATE_RECOVERED:
            // These are terminal states. No logic is performed here.
            // They are only exited by explicit commands (CLEAR_ERRORS, ENABLE, or RESET).
            break;
    }
}
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
int main(void) {
    // Initialize all hardware and controllers.
    pressboi.setup();

    // Enter the main application loop, which runs forever.
    while (true) {
        pressboi.loop();
    }
}

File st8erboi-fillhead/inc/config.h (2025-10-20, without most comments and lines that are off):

#pragma once
#include "ClearCore.h"
#define LOCAL_PORT                      8890      ///< The UDP port this device listens on for incoming commands.
#define MAX_PACKET_LENGTH               1024      ///< Maximum size in bytes for a single UDP packet. Must be large enough for the longest telemetry string.
#define RX_QUEUE_SIZE                   32        ///< Number of incoming messages that can be buffered before processing.
#define TX_QUEUE_SIZE                   32        ///< Number of outgoing messages that can be buffered before sending.
#define MAX_MESSAGE_LENGTH              MAX_PACKET_LENGTH ///< Maximum size of a single message in the Rx/Tx queues.
#define TELEMETRY_INTERVAL_MS			100       ///< How often (in milliseconds) telemetry data is published to the GUI.
#define STATUS_MESSAGE_BUFFER_SIZE      256       ///< Standard buffer size for composing status and error messages.
#define POST_ABORT_DELAY_MS             100       ///< Delay in milliseconds after an abort command to allow motors to come to a complete stop.
#define INJECTOR_PITCH_MM_PER_REV       5.0f      ///< Linear travel (in mm) of the injector plunger for one full motor revolution.
#define PINCH_PITCH_MM_PER_REV          2.0f      ///< Linear travel (in mm) of the pinch valve actuator for one full motor revolution.
#define PULSES_PER_REV                  800       ///< Number of step pulses required for one full motor revolution (dependent on microstepping settings).
#define STEPS_PER_MM_INJECTOR           (PULSES_PER_REV / INJECTOR_PITCH_MM_PER_REV)   ///< Calculated steps per millimeter for the main injector drive.
#define STEPS_PER_MM_PINCH              (PULSES_PER_REV / PINCH_PITCH_MM_PER_REV)      ///< Calculated steps per millimeter for the pinch valve mechanism.
#define MAX_HOMING_DURATION_MS          100000    ///< Maximum time (in milliseconds) a homing operation is allowed to run before timing out.
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

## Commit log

2025-10-20 simulator and pressboi device updates
2025-11-03 Release v1.0.0 - Initial Pressboi firmware
    - Dual-motor press control system
    - UDP/Ethernet + USB Serial communication
    - Command protocol with pause/resume/cancel
    - Real-time telemetry and force monitoring
    - Auto-generated protocol files from JSON schemas
2025-11-03 Switch to dynamic badges now that repo is public
2025-11-03 Fix: Remove unused doneMsg variable
    [motor_controller.cpp]
2025-11-03 Add abort and clear_errors commands to command parser
    - Added CMD_ABORT and CMD_CLEAR_ERRORS to commands enum
    - Added handlers in dispatchCommand
    - Standardized DONE messages: 'abort' and 'clear_errors'
    - Allow CLEAR_ERRORS to execute in ERROR state
    [pressboi.cpp]
2025-11-03 Refactor: abort removed, cancel handles stopping, reset replaces clear_errors
    - Removed CMD_ABORT - cancel command now handles emergency stops
    - Renamed clear_errors to reset (CMD_RESET)
    - Cancel command now calls abort() to stop motion
    - Reset command sends 'PRESSBOI_DONE: reset'
    - Updated error state to allow CMD_RESET
    [pressboi.cpp]
2025-11-03 Release v1.1.0 - Command improvements and telemetry fixes
    [motor_controller.cpp]
2025-11-05 v1.2.1 - Force sensor configuration and telemetry (missing files)
2025-11-06 Release v1.3.0
    - Added hardware watchdog timer (SAMD51 WDT) with 128ms timeout
    - Added STATE_RECOVERED for watchdog timeout handling
    - Added test_watchdog command for system testing
    - Added motor torque force limiting (no load cell required)
    - Added torque-to-force conversion (Torque% = 0.0335 Ã— kg + 1.04)
    - Added force_mode parameter (motor_torque or load_cell)
    - Added split force telemetry fields
    - Added force source field to telemetry
    - Modularized watchdog functions
    - Centralized limit handling for both force modes
    - Load cell checks conditional based on force mode
    - Fixed torque display flickering during active moves
    [config.h, motor_controller.cpp]
2025-11-13 Fix critical NVM byte offset bug and implement missing commands
    - Fixed NVM location indexing: NvmLocations enum uses BYTE offsets, not word indices
    All NVM reads/writes were using wrong offsets (0,1,2,3 instead of 0,4,8,12)
    - Implemented dump_nvm command with proper hex dump display and calibration summary
    - Implemented reset_nvm command to erase all NVM locations
    - Implemented set_force_zero command for both load cell and motor torque modes
    - Fixed ForceSensor tare() - Rugeduino no longer supports tare command
    - Fixed dump_nvm hanging issue by pre-reading all NVM values before formatting
    - Updated code to show old/new offset values in set_force_zero output
    - All NVM operations now use co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
    [motor_controller.cpp, pressboi.cpp]
2025-11-14 Remove blocking delay from abortMove() to prevent watchdog timeout
    [motor_controller.cpp]
2025-11-14 Add safety timeouts and iteration limits to prevent blocking operations
    [motor_controller.cpp]
2025-11-14 Use home position (0mm) as default retract position if not explicitly set
2025-11-14 Remove 'Motor: ' prefix from all motor controller status messages
2025-11-14 Feed watchdog during network initialization to prevent startup timeout
    [pressboi.cpp]
2025-11-14 Initialize watchdog after comms setup to avoid timeout during network initialization
    [pressboi.cpp]
2025-11-15 Add endpoint variable to track position where moves end or force triggers
2025-11-15 Fix retract/abort actions to always retract even when move completes normally (not just when force limit is hit)
    [motor_controller.cpp]
2025-11-15 CRITICAL FIX: Clear force_action before starting retract to prevent infinite loop and watchdog timeout
    [motor_controller.cpp]
2025-11-15 Fix abort action to only retract when force limit is hit, not on normal completion
    [motor_controller.cpp]
2025-11-15 Release v1.6.0: Add endpoint telemetry, fix infinite retract loop and abort behavior
    [config.h]
2025-11-15 Increase watchdog timeout from 128ms to 256ms to prevent false triggers during startup
    [pressboi.cpp]
2025-11-15 Delay watchdog initialization by 10 loop iterations to prevent false triggers during startup
    [pressboi.cpp]
2025-11-15 Fix TX queue processing to handle multiple messages per loop iteration
    [pressboi.cpp]
2025-11-15 Fix set_retract bug: use LONG_MIN sentinel instead of 0 to detect unset retract position
    [motor_controller.cpp]
2025-11-15 Disable watchdog before rebooting to bootloader to prevent timeout during firmware flash
    [pressboi.cpp]
2025-11-18 v1.7.0: Move device definition to firmware repo, fix retract_pos telemetry
2025-11-18 v1.7.0: Fix USB telemetry and add dual connection support
    - Fix firmware not sending telemetry over USB when GUI not discovered
    - Implement chunked USB message sending for large telemetry packets
    - Fix network discovery to allow reconnection after initial connection
    - Fix retract_pos reporting garbage when motor not homed
    - Add simultaneous USB and network telemetry streaming
    - Update device definition GUI to prevent double @ in IP display
    - Remove unused debug variables
    [config.h, pressboi.cpp]
2025-11-19 v1.8.0 - USB buffer deadlock fix and device naming portability
    [config.h]
2025-11-19 Fix USB host detection - mark connected when commands received
    - Move USB health tracking from static variables to class members
    - Implement notifyUsbHostActive() to immediately mark host as connected
    - Call notifyUsbHostActive() when USB commands are received
    - Prevents firmware from staying in 'host disconnected' state after app restart
    - Version bump to 1.8.1
    [config.h]
2025-11-19 Fix watchdog timeout - avoid blocking USB.Send() calls in host detection - v1.8.3
    [config.h]
2025-11-19 Fix USB host detection to run every loop iteration
    - Moved USB buffer health check outside message queue processing
    - Health check now runs every loop regardless of queue state
    - Prevents firmware staying in 'disconnected' state after app restart
    - Eliminates need for power cycling microcontroller
    Version: 1.8.5
    [config.h]
2025-11-19 Add additional_done_on to move commands
    - Declares that move_abs/move_inc with force_action=retract will send additional retract DONE
    - Moves device-specific behavior into device definition
    - Enables generic script processor to handle this without hardcoded logic
2025-11-20 Add comprehensive error logging and USB recovery
    - Add ErrorLog system (100 entries, 8.8KB circular buffer) with DEBUG/INFO/WARN/ERROR/CRITICAL levels
    - Add HeartbeatLog (2880 entries, 23KB) for compact 24-hour USB/network status tracking
    - Add dump_error_log command to retrieve diagnostic logs over network/USB
    - Implement USB recovery mechanism: auto-detect stuck buffer and reset port
    - Fix watchdog timeout during USB recovery by feeding watchdog and removing blocking delay
    - Add 500ms fault detection grace period after clearing motor faults
    - Feed watchdog during USB port close/reopen operations
    - Log USB events, state changes, and command dispatch for debugging
    - Update class reference wi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
    [pressboi.cpp]
2025-11-20 Update changelog for v1.10.0
    - Error logging system with circular buffer
    - Heartbeat log for 24-hour USB/network status tracking
    - dump_error_log command
    - USB auto-recovery mechanism
    - Motor fault detection grace period
    - Watchdog fixes during USB recovery
2025-11-20 Fix watchdog timeouts: limit network packet processing and add breadcrumbs
    CRITICAL FIXES:
    - Limit EthernetManager::Refresh() to 10 packets/call (was unbounded)
    - Limit processUdp() to 10 UDP packets/call (was unbounded)
    - Remove watchdog feeding from USB recovery (defeats watchdog purpose)
    DIAGNOSTICS:
    - Add NETWORK_REFRESH, USB_SEND, USB_RECONNECT, USB_RECOVERY breadcrumbs
    - Track USB reconnection and message sending with breadcrumbs
    The unbounded network processing was causing watchdog timeouts when:
    1. USB reconnects after dock unplug/replug
    2. Network accumulated packets during USB disconnect
    3. All packets processed in one loop iteration exceeding 128ms threshold
    Now packets are spr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
    [pressboi.cpp]
2025-11-20 Fix compilation: move breadcrumb definitions to config.h header
    Moved WD_BREADCRUMB_* definitions from pressboi.cpp to config.h
    so they are visible to all source files including comms_controller.cpp.
    This fixes compilation errors:
    - WD_BREADCRUMB_USB_RECONNECT was not declared
    - WD_BREADCRUMB_USB_SEND was not declared
    - WD_BREADCRUMB_USB_RECOVERY was not declared
    [config.h, pressboi.cpp]
2025-11-21 Aggressively reduce packet limits to 1 per call + add motor update breadcrumb
    - Reduced MAX_UDP_PACKETS_PER_CALL from 3 to 1
    - Reduced MAX_PACKETS_PER_CALL (network) from 3 to 1
    - Added WD_BREADCRUMB_MOTOR_UPDATE inside updateState() for granular debugging
    - Even 3 packets per call was causing 128ms+ cumulative time on USB reconnection
    - 1 packet per call is extremely conservative but necessary for reliability
    - Network throughput further reduced but watchdog protection maximized
2025-11-21 Add extensive breadcrumbs throughout firmware for precise timeout diagnosis
    Added breadcrumbs to:
    - enqueueRx, enqueueTx (0x1D, 0x11)
    - processTxQueue sections (0x14-0x17)
    - processUdp packet read (0x1C)
    - processUsbSerial (0x1E-0x1F)
    - dispatchCommand, parseCommand (0x18-0x19)
    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
2025-11-21 Fix TX queue overflow when dumping logs
    - Temporarily disable watchdog during dump_error_log command
    - Log dumps can take >500ms for large logs (100+ entries)
    - Watchdog timeout is only 100ms - would cause reset mid-dump
    - Watchdog is ONLY disabled for this diagnostic command
    - Add 5ms delay per error entry to prevent TX queue overflow
    - Add 50ms delay every 10 heartbeat entries to prevent overflow
    - Log messages confirm watchdog disable/re-enable
    - TX queue: 32 messages, log dumps: 100+ messages
    This is acceptable for a diagnostic command that should only be run
    when troubleshooting - watchdog integrity maintained for all normal operations.
    [pressboi.cpp]
2025-11-22 Add set_polarity command to flip coordinate system (v1.11.0)
    - Added set_polarity command with 'normal' and 'inverted' options
    - Coordinate system polarity now persists in NVM (location 3)
    - Applies motor direction inversion via PolarityInvertSDDirection()
    - All moves and home operations respect polarity setting
    - Firmware version bumped to 1.11.0
    [config.h, motor_controller.cpp, pressboi.cpp]
2025-11-26 v1.11.3: Increase watchdog timeout to 256ms and optimize USB chunking
    - Increased watchdog timeout from 128ms to 256ms for better stability
    - Reduced USB chunk timeout from 10ms to 3ms to prevent blocking
    - Prevents watchdog timeouts during USB reconnection on app restart
    - Total USB blocking time now ~30ms (well within 256ms watchdog limit)
    [config.h, pressboi.cpp]
2025-11-26 fix: Delay auto-homing by 2s after boot to prevent watchdog timeout during app restart
    Critical fix for watchdog timeout issue that occurred when app restarted and triggered
    immediate auto-homing. The 2-second delay allows USB/network to stabilize and message
    queues to clear before initiating the homing sequence.
    Fixes #watchdog-on-restart
    [config.h, pressboi.cpp]
2025-11-28 v1.14.0: Press report system and strain calibration commands
2025-11-28 Add toggle button for polynomial fit trace (hidden by default)
2026-01-25 Motor controller refactoring and report improvements
2026-03-18 v1.14.1: Fix NVM address calculation, telemetry hardcodes, dead code cleanup
    Fix setMachineStrainCoeffs() NVM address to use (8+i)*4 stride,
    replace hardcoded torque offset/scale with member variables and
    correct 2000N clamp, remove unused USB mirror declarations from
    CommsController.
    Made-with: Cursor
    [config.h, motor_controller.cpp]
2026-04-20 Add PCB for load cell adapter
    [transducer-pcb JLC BOM.csv, transducer-pcb Odoo BOM.xlsx, transducer-pcb Stock Info.xlsx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]
2026-04-20 Rev B PCBA and move arduino file to folder
    [transducer-pcb JLC BOM.csv, transducer-pcb Odoo BOM.xlsx, transducer-pcb Stock Info.xlsx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]
